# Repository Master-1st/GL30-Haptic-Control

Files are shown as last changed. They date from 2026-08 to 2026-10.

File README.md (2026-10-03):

# GL30 Haptic Control

**2026-10-03 update:** [Current offline delivery](docs/offline-delivery-20261003-cn.md), [Altium PCB guide](docs/pcb-drawing-guide-20261003-cn.md), and [A-board native schematic snapshot](hardware/pcb/stm32-foc-a-altium-r6/README_CN.md). Current ESP32/STM32 host suites have 8/15 cases respectively; frozen firmware builds passed. This candidate is unflashed and the custom PCB is not laid out or routed.

English · [简体中文](README_CN.md) · [Documentation](docs/README.md) · [Roadmap](ROADMAP.md) · [Contribute](CONTRIBUTING.md)





**Give rotary controls a programmable feel.**

GL30 Haptic Control is an open-source haptic knob project in development for desktop controls, creative tools, and everyday interactions. Built around a CubeMars GL30 brushless motor, an encoder and closed-loop control produce virtual detents, damping, spring return, and soft limits.

The aim is to let one knob change its feel with the application: distinct steps for volume, smooth movement through a timeline, or resistance at a parameter's boundary. A round display provides context, while physical feedback helps you feel the operation.

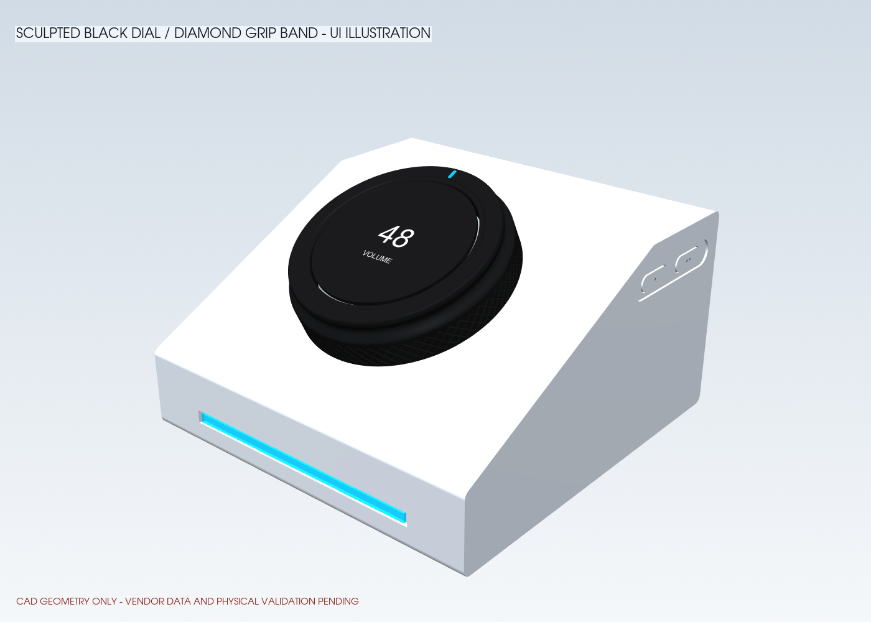
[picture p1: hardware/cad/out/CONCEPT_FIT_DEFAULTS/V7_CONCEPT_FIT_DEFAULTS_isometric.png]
GL30 Haptic Control concept


*Existing concept render, not a finished-device photo. It does not include the new press mechanism or bottom light ring.*

## Different actions, different feel

- **Detents:** configurable positions and strength for selection and stepped adjustments.
- **Damping:** resistance for continuous control, from careful adjustment to faster movement.
- **Spring return:** a centered interaction for exploring playback speed or directional input.
- **Soft limits:** resistance at parameter boundaries, making a range tangible.

These behaviors are organized around **Haptic Profiles**. The goal is to separate the feel an application requests from low-level motor control, so developers can adjust configurations and compose interactions.

## What could you use it for?

These are priority application directions; their software and whole-device integrations are still in development.

| Application | Intended interaction |
| --- | --- |
| **Volume and media** | Stepped volume, on-knob status, and press-to-control playback |
| **Focus timer** | One revolution sets one hour; orange progress rings represent additional turns, with press-to-start/pause |
| **Video and creative tools** | Timeline navigation, frame stepping, and parameter adjustment with task-specific feel |
| **Smart home** | Control lights, temperature, or scenes through platforms such as Home Assistant |

GL30 is the first reference device. The longer-term direction is to bring these haptic configurations and application interfaces to other physical controls. See the [feature research](docs/feature-research.md).

## Screen, light, and motion

The interaction direction combines a black rotary ring, a black screen surround, and RGB light emerging from the knob-to-base gap. At least 24 LEDs form a fixed ring: the illuminated position follows the measured knob angle instead of a painted marker. Pressing the ring provides confirmation and timer controls.

Expressive screen motion uses anticipation, elastic exaggeration, and rebound to respond to the user's actions. When off, the display should blend into the black surface.

The new press mechanism and light ring are not yet implemented in CAD or firmware. Board and assembly details belong in the separate [design plan](docs/knob-press-rgb-architecture-cn.md).

## A platform to build on

- **Separate control and UI roles:** STM32G474 handles the motor and haptics; ESP32-S3 handles the display, applications, and connectivity.
- **Inspectable configurations:** Profile formats, examples, and validation tools support experimentation with application-specific feel.
- **Start without hardware:** protocol checks, a device simulator, host tests, and a separately buildable UI model run on a computer.
- **Open project materials:** firmware, application-layer sources, protocol definitions, prototype CAD, and engineering notes have dedicated entry points.

## Current progress

The project is a **pre-alpha engineering prototype**.

- **Bench-tested:** bounded GL30/AS5048A closed-loop operation, basic haptic modes, and stop/communication-loss shutdown.
- **Available offline:** the current protocol, Profile validation, device simulator, same-source KK C UI, NVS preferences, control-owner handoff, and product-port protection regressions.
- **Engineering materials:** the seven-page A-board Altium schematic without test points, BOM and placement guide, plus R21 nominal mechanical models and the corrected assembly manual.
- **Next:** finish four A-board pad footprints and placement, complete B/C circuits, and validate the custom board, display, mechanism and assembled haptic feel on hardware.

This is not yet a ready-to-replicate kit. Bench results do not establish finished-device feel, thermal performance, battery life, or durability. See the [bench report](docs/bench-validation-20260908-haptic25-extended-cn.md) and [roadmap](ROADMAP.md).

## Start exploring

- [UI model and host preview](firmware-esp32/ui/README.md)
- [Haptic configuration compatibility](docs/profile-compatibility.md)
- [Prototype CAD and printing notes](hardware/cad/README_CN.md)

To run software checks from the repository root, use Node.js 24+ and pnpm 11.19+:

```bash
pnpm install --frozen-lockfile
pnpm verify
```

These commands check the protocol, Profiles, and simulator without hardware. They do not launch a GUI or drive a motor.

Go deeper: [STM32 motor core](firmware-stm32/README.md) · [PC Companion](pc-companion/README.md) · [Protocol](protocol/schema/protocol-v1.md) · [Documentation](docs/README.md).

## Help shape the feel

Contributions to haptics, application adapters, screen animation, mechanics, tests, and documentation are welcome. Use cases and reproduction reports are valuable too. Start a [Discussion](https://github.com/Master-1st/GL30-Haptic-Control/discussions) or read the [contributing guide](CONTRIBUTING.md).

[SmartKnob](https://github.com/scottbez1/smartknob) and [X-Knob](https://github.com/SmallPond/X-Knob) are important interaction references; sources are documented in the [feature research](docs/feature-research.md). GL30 hardware parameters and validation remain independent.

## License

Original material is licensed under [Apache-2.0](LICENSE). Third-party components retain their own licenses; see [THIRD_PARTY_NOTICES.md](THIRD_PARTY_NOTICES.md). Obtain vendor material from its [original sources](hardware/cad/vendor/SOURCE_MANIFEST.md).

This project is independent of the referenced vendors and projects and does not imply their endorsement.

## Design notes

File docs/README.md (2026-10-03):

# Engineering documentation

[当前离线交付](offline-delivery-20261003-cn.md) · [A 板怎么画](pcb-drawing-guide-20261003-cn.md) · [公开项目入口](../PROJECT_INDEX_CN.md)

当前进度先看 [2026-09-27 项目进度整理](project-progress-20260927-cn.md)；按模块查找见 [项目索引版](../PROJECT_INDEX_CN.md)。[项目全量单文件版](../PROJECT_ALL_IN_ONE_CN.md)含历史首批 BOM 和早期方案，不作为最新完成状态或整套采购指令。

原 `G:\Agent\workspace` 的 GL30 文件已归回项目，见 [统一入口与版本关系](../outputs/workspace-consolidated-20260927/README_CN.md)：包含 R12–R20、装配手册、正式板指南和独立发布准备工作区。9/27 已建立 [R21 合并机械候选](../outputs/r21-integrated-mechanical-20260927/README_R21_先看.md)，仍需实物验证。

A 板当前使用 [原生 AD 工程，无测试点](../hardware/pcb/stm32-foc-a-altium-r6/README_CN.md)、[AD ZIP 与验证](../outputs/a-schematic-altium-20260927/README_CN.md)：7 页、146 个位号，AD 实际连接比对通过；已关联用户库封装 142/146 个位号，仍有 4 个封装及 30 个驱动源警告，未完成投板审核。此前 [KiCad/PDF 版](../outputs/a-schematic-kicad-20260927/README_CN.md)是含测试点的历史源稿。PB9/PA12/PC13 与母线/NTC 已统一，固件验证见 [接口核对包](../outputs/product-interface-20260927/README_CN.md)。[OSHWHub 类似项目对照](../hardware/pcb/stm32-foc-a/开源项目对照.md)列出可参考部分及差异。

The detailed engineering notes are currently Chinese-first while the public repository overview and roadmap are bilingual. Contributions that add accurate English counterparts are welcome.

面向首次访问者的介绍见[中文首页](../README_CN.md) / [English overview](../README.md)。本次首页写法的[类似项目原文与改写对照](readme-reference-cn.md)单独保留，不与工程方案混排。

## Read in this order

最新屏幕状态及证据见 [9/27 汇总](project-progress-20260927-cn.md)：9/17 连续菜单记录 **59.980 FPS / 60 秒**，目标 60 Hz，显示错误、输入丢弃和电机发送均为 0；已加入彩色图标、中英切换及设置页。电机未参与此性能验收。[9/16 的 61.587 FPS 显示链审计](esp32-60fps-optimization-20260916-cn.md)和 [9/15 的 35.706 FPS 记录](esp32-dirty-audit-20260915-cn.md)保留为历史阶段证据，不能混合版本和测试条件。

早期产品交互方向见 [旋环按压、24 RGB 与板件装配方案](knob-press-rgb-architecture-cn.md)（2026-09-09）；后续机械实物反馈和正式板路线以 [当前汇总](project-progress-20260927-cn.md)为入口，均不自动继承台架验收。

最新离线实现见 [H26 行为层与 ESP 动画](haptic26-ui-offline-20260908-cn.md)：新源码未烧录，不继承 H25 的硬件验收。

当前实测先看 [2026-09-08 H25 扩展验收](bench-validation-20260908-haptic25-extended-cn.md)：37 组新增冻结采样、定时边界、ACTIVE STOP/失联关断、20 次重复运行和无出力通信/准备状态压力测试通过。此前 H25 电流阶梯见 [基线报告](bench-validation-20260907-haptic25-cn.md)，H8/H10 及中间失败保留为历史。

整体进度以 [9/27 汇总](project-progress-20260927-cn.md)为入口；[9/9 总进度](project-progress-review-20260908-cn.md)、[9/8 原始审查](project-progress-review-20260908-history-cn.md)与 [9/5 重评](project-reassessment-cn.md)保留为历史，不再作为当前源码或首测操作基线。

1. [`feature-research-cn.md`](feature-research-cn.md) / [`feature-research.md`](feature-research.md) — haptic-first product scope, public demand, integrations, and explicit non-capabilities.
2. [`current-architecture-cn.md`](current-architecture-cn.md) — active architecture and source-of-truth order.
3. [`evidence-boundary.md`](evidence-boundary.md) — what each evidence level does and does not prove.
4. [`hardware-gates.md`](hardware-gates.md) — staged release gates before energized testing.
5. [`cubemars-vendor-confirmation-cn.md`](cubemars-vendor-confirmation-cn.md) — unresolved motor/encoder questions.
6. [`stm32-pinout-and-schematic-cn.md`](stm32-pinout-and-schematic-cn.md) — current pin and schematic input table.
7. [`stm32-bringup-and-tuning-cn.md`](stm32-bringup-and-tuning-cn.md) — post-vendor bring-up and tuning order.
8. [`../hardware/motor-control/GL30_KV290_ARRIVAL_BASELINE_CN.md`](../hardware/motor-control/GL30_KV290_ARRIVAL_BASELINE_CN.md) — received motor parameters, consistency checks, safe defaults, and first-test gates.
9. [`waveshare-baseline.md`](waveshare-baseline.md) — application-module baseline.
10. [`NUCLEO + TI EVM FOC bring-up`](../firmware-stm32/bench/NUCLEO_G474RE_FOC/README_CN.md) — current HAPTIC25 NUCLEO-G474RE firmware, exact EVM/encoder pin map, restricted console and evidence boundary; ALIGN, short bidirectional IQ and eight-mode hardware smoke pass, not product/tactile acceptance.

Validation-board drawing and test instructions live under [`hardware/drv8316r_bench`](../hardware/drv8316r_bench/README_CN.md).

## Documentation rule

Plans, calculations, simulations, builds, CAD checks, bench measurements, and external reproductions must remain distinguishable. When a result changes, update the narrowest source document and link the raw evidence rather than copying the claim into several files.

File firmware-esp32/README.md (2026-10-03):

# GL30 ESP32-S3 屏幕固件

2026-10-03 公开上传入口：[当前源码与冻结离线交付](../docs/offline-delivery-20261003-cn.md)，[A 板画板指南](../docs/pcb-drawing-guide-20261003-cn.md)。本机 outputs 历史归档不全部随 Git 分发。

2026-10-02 冻结历史：[设置保存、STM32控制权交接与验证](../outputs/esp32-settings-storage-20261002/README_CN.md)。采用ESP-IDF NVS保存13项配置，启动恢复不恢复运行/授权状态；运行写入须有精确RELEASE回显和显示DMA独占。无对端不写Flash，握手完成作废旧ARM，恢复后须新人工请求。三配置各8/8、ESP-IDF构建通过，未烧录。线协议已统一72/44/24字节；千问第一轮架构意见与当前代码意见分别记录，最新实际评审范围见交付。本段评审仅描述该次冻结结果，不代表本次重新调用模型。

2026-10-02 零回显阶段历史：[只读确认、重复停止修订与验证](../outputs/esp32-zero-confirm-review-20261002/README_CN.md)。两路回显须在完整UART接受之后且年龄小于20ms；新STOP换nonce，旧回显不能恢复确认。该阶段三配置各6/6，未烧录；当时未接NVS，已由上方续进实现。软件回显仍不是实体关桥证据。

2026-10-02 输入链路阶段：[停止请求、64位ARM令牌与回归](../outputs/esp32-input-stop-review-20261002/README_CN.md)。`MOTOR OFF`在解析时先提交停止，输入队列满时也立即记录撤授权；停止前开始的半行或排队ARM会失效。溢出清理取消手势并清队列，须在清理后重新发ARM；普通OFF后新的人工ARM仍可被接受。三种主机配置各6/6、专项294项检查与ESP-IDF构建通过，未烧录；最后复核至UART提交间隙的在途帧不能召回，不声称物理停机延迟。该阶段Qwen按当时要求关闭，当前授权规则以上方新包为准。

2026-10-02 状态显示续进：[电机状态、灯效入口、同源画面与验证](../outputs/esp32-motor-feedback-20261002/README_CN.md)。底部显示 OFFLINE/CHECKING/ALIGN/READY/ACTIVE/FAULT/UNKNOWN 及中文提示；有效 FAST 接收年龄达到 20 ms 时投影为失联，读取快照再次检查。失联时的诊断零值表示没有当前证据，不能据此清故障或授权。状态只更新显示，不暂停计时、不取消手势。八项菜单的“设置 → 灯效”入口已按普通输入走通。主机检查和 ESP-IDF 构建通过，本版未烧录。

2026-10-02 电机链路续修：UI与 READY/ACTIVE FAST 健康时，未 armed 也发送固定 nonce 的零限值心跳；STM 同步将有效零限值定义为撤使能/关桥，正常空闲不会因停止发包而锁存通信故障。MOTOR OFF、反馈失配或健康失效后，通信恢复不能自动授权出力；正常页面切换保留已有人工授权。产品仍未对齐时不发送该心跳。见[源码、回归、构建与审查记录](../outputs/idle-fault-and-link-review-20261002/README_CN.md)。本轮未烧录，未测FPS或实体电机手感。

2026-09-27 界面修订：[代码审查、前后画面与验证](../outputs/esp32-ui-review-20260927/README_CN.md)。主目录已合入归并资料中的桌面/月历调整，并统一灰度字体、菜单图标和圆屏设置布局，修复多圈反转蓝灯位置与中文标题缺字。主机和浏览器检查、ESP-IDF 构建通过；本轮未烧录，旧版本 FPS 不代表这版性能。

[9/17 发布准备工作区](../outputs/workspace-consolidated-20260927/firmware/GL30-Haptic-Control-release-20260917/docs/firmware-status-20260917.md)保留独立 Git 关联和未提交内容；仅合入上述 UI 相关文件，没有用整个工作区覆盖当前主目录。版本关系见 [整理入口](../outputs/workspace-consolidated-20260927/README_CN.md)。

当前实际固件入口为根目录 ESP-IDF 工程：`main/app_main.c` → `components/gl30_ui` → `KK_UI` → RGB565 版 `KK_OLED` → CO5300/CST820 BSP。目标为 Waveshare ESP32-S3-Touch-AMOLED-1.32，466×466。

[当前进度与 9/17 最新验证记录](../docs/project-progress-20260927-cn.md) · [9/16 60 FPS 显示链优化与代码审计（历史阶段）](../docs/esp32-60fps-optimization-20260916-cn.md) · [9/15 按帧跳过比较与代码审计（历史基线）](../docs/esp32-dirty-audit-20260915-cn.md) · [9/15 菜单与性能优化（历史阶段）](../docs/esp32-menu-optimization-20260915-cn.md) · [9/15 自动校时](../docs/esp32-auto-clock-and-kk-animations-20260915-cn.md) · [9/15 USB 实机调试](../docs/esp32-usb-bringup-20260915-cn.md) · [9/14 接入、构建与边界](../docs/esp32-kk-integration-20260914-cn.md) · [固件同源预览说明](ui/kk-preview/README_CN.md)。预览显示同一份 C 代码的实际画布。此前 `ui/src` 的 LVGL 组件和 `ui/preview` 的 SVG 演示是历史设计参考，不在新固件构建链路内，也不是运行时备用实现。

2026-09-15 已连接 Type-C、备份原始 8 MB Flash，并通过 COM11 烧录与读取 USB 状态。CO5300、CST820 和 PSRAM 初始化已在实机日志中确认；实屏目视、色序、触摸方向和实际触摸手势仍待确认。闹钟、手感与天气联网保留待接入状态。当前已编译接入默认未使能的 STM32 菜单链路，20 项 USB 功能与连续菜单测试中 `motor_tx=0`；没有烧录 STM32 或驱动外部灯环。

9/15 已验证当前 Windows 用户的 Type-C 自动校时程序与复位恢复；Wi-Fi/SNTP 尚未接入。KK_UI 保持 Custom 页面与统一刷新调度，软件菜单复用 Q12 缓动，电机 q/f 反馈直接决定视觉相位。9/16 完成 wire-native RGB565、80 MHz QSPI、64 行传输、三帧缓存及后台清屏等优化，见 [该阶段审计](../docs/esp32-60fps-optimization-20260916-cn.md)。9/17 进一步加入彩色图标、双语和设置页，当前目标为 **60 Hz / 16,667 μs**；最新连续菜单测试 **59.980 FPS / 60 秒**，`frame_errors=0`、`input_drops=0`、`motor_tx=0`。这是屏幕链路记录，尚未完成人工视觉、实际手势、真实 STM32 满流量与电机手感验收；详见 [当前进度中的原始记录与边界](../docs/project-progress-20260927-cn.md)。

已冻结接口：

- USART 5 Mbaud、8N1、全双工 DMA；不实现旧草案的 6 Mbaud。
- Waveshare J1-11 `ESP TX -> STM PB11 RX`。
- Waveshare J1-12 `ESP RX <- STM PB10 TX`。
- GP1 接经开漏缓冲后的 `SYS_FAULT_N`；GP0 首版 DNP；GP2 禁止外部驱动。
- ESP UART0 启动日志必须关闭或移动，不能污染 V1 二进制链路。
- 3.3 V 电源不通过扩展口互相回灌，只共地和信号。

后续硬件闭环：验收实屏与触摸后，联调已有 UART0 接入及新增 HAPTIC_STATE 生效反馈。屏幕固件默认不授权出力；只有显式调试使能后才可能建立有力矩的菜单会话，健康 READY/ACTIVE 链路可先发送零限值心跳。编译和主机仿真不代表实体电机已验收。计时器回旋目标和零点止挡意图已经在界面模型中计算；电流环与触觉闭环仍由 STM32 承担，不能用触摸输入或电机端角度观察自动冒充手动施力。

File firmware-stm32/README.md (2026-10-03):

# GL30 STM32 固件：产品工程与 NUCLEO 联调工程

2026-10-02 当前离线续进：[控制权交接与完整验证](../outputs/esp32-settings-storage-20261002/README_CN.md)。普通命令匹配64位租约，ACQUIRE后先接受精确全零命令，RELEASE期间关闭输出并暂停周期遥测而保留保护/故障；第二临界区重新检查10ms命令年龄。三种主机配置各15/15，CET6产品和NUCLEO台架构建均0错误0警告。产品电角零位宏仍为0，本轮未烧录、不放行出力。

当前两个硬件目标均由 STM32CubeMX 生成，使用 Keil MDK-ARM 与 ARMCLANG 6.21；外设和高频路径采用 STM32 LL。它们是不同硬件端口，不是历史版本。旧 HAL/CMake ARM 工程不作为活动路径。

**手上是 NUCLEO-G474RE + TI DRV8316REVM 时，从 [FOC 联调工程](bench/NUCLEO_G474RE_FOC/README_CN.md) 开始。** 板上为 HAPTIC25：20 kHz 电流环、AS5048A SPI、受限 ALIGN/双向 IQ/八模式已通过实测。2026-09-08 追加定时边界、重复运行、运行中 STOP 和失联关断，详见 [扩展验收](../docs/bench-validation-20260908-haptic25-extended-cn.md)。不要把下面 CET6 产品板工程烧到 NUCLEO，也不要混用引脚表。

## CET6 产品板当前实现

- 160 MHz；TIM1 40 kHz 中心对齐互补 6-PWM，默认死区 500 ns。
- TIM1 CH4/TRGO2 同步 ADC1/2/3 注入采样；40 kHz FOC/SVPWM。
- TIM6 4 kHz 角度观测，TIM7 2 kHz 触觉与安全调度。
- DRV8316：SPI3 Mode 1、5 MHz；USART3：5 Mbaud DMA；I2C1：400 kHz。
- DRVOFF 上电关断、TIM1 MOE 默认关闭、PB12/TIM1_BKIN 低有效、故障锁存。
- 9/27 已购器件接口统一：PB9 为 MOTOR_PWR_EN，PA12 为 nSLEEP，默认均低；PC13 低速推挽驱动 U7，未就绪/故障为低。母线 ADC 倍率 11，10k/B3950 NTC 在 200 Hz 任务换算。
- 产品编码器实现为 `drivers/factory_encoder_as5048a.c`，复用共享 AS5048A 编解码：SPI1 Mode 1、16 位、2.5 MHz，TIM6 4 kHz 执行 ANGLE→DIAG→NOP。角度和诊断回复均检查奇偶校验与 EF；异常不刷新最后成功的时间戳。整轮 50 µs 为超时判据，实板时序尚未验收。只读接入不解除供电、驱动配置及电角零位门控。
- 10/02 驱动复查：SPI3 增加 FIFO 上限、共用超时和 CS 间隔；配置与 arm 可被故障取消。普通停转保留配置，实际休眠/断电前明确使其失效；arm 不再自动清障。致命异常入口增加紧急关断。见[本轮修订、三方审查与验证](../outputs/driver-startup-review-20261002/README_CN.md)。

## CET6 产品板 CubeMX/Keil 工程

10/02 电流采零续修：移除驱动休眠时的开机平均，改为配置/电源/休眠资格检查、10 ms 稳定等待、512 组三相样本与均值/波动验收；掉电或故障清除零偏，50 ms 期限也由前台检查。过压保护在采零之前执行，零偏的三通道快照在临界区内取得。见[采零阶段证据](../outputs/current-zero-review-20261002/README_CN.md)。

10/02 启动流程续修：逻辑、温度、编码器和新鲜 ADC 合格后，固件自动请求母线；母线连续稳定 10 ms 后唤醒驱动，等待 10 ms、配置读回、完成采零，再在 MOE=0/六路 PWM 输入低的条件下确认驱动状态。仅首次 NPOR 可受控确认一次，其他故障不自动清除；失败后关断且不重试。此准备过程不会开启 PWM，出力仍要求电角零位合格及 ESP 的显式启用。当前电角零位仍无效，未烧录、未验收实物时序。见[本轮实现及验证记录](../outputs/power-startup-review-20261002/README_CN.md)。

收到的命令记录本地接收时刻；排队达到 10 ms 的命令不刷新通信心跳，首次 READY 之前接收的命令不能触发 arm。开机 50 ms 仍无新鲜 ADC 会锁存故障；故障态只有在输出与电源请求均读回关断、2 kHz 安全调度仍有进度时才继续喂狗。IWDG/WWDG 复位会在下一次准备前锁存启动故障，避免自动重试供电。主循环或安全调度失去进度仍由看门狗复位。

10/02 空闲与停止续修：准备完成且 DRVOFF 实际为低时，2 kHz 监督和前台监测会锁存共享 PB12 低；verify 返回到 COMPLETE 发布前也复查。普通关桥的 DRVOFF 高不会被该检查误判；重新启用事务中，仅当实际 MOE 和驱动输出均关闭时暂由驱动最终读回把关，避免把正常释放稳定期误判。一旦任一输出指示开启即继续监视，事务返回后标记清除。TIM7 不新增 SPI/等待。有效零力矩上限命令刷新租约并立即撤 arm、清零 FOC、关桥，不能使能 PWM；正限值保留原门控。ESP 健康空闲时发送零心跳，失效后不自动恢复出力。见[本轮证据与审查](../outputs/idle-fault-and-link-review-20261002/README_CN.md)及[协议约定](../protocol/schema/protocol-v1.md)。未烧录，电角零位宏仍为0。

- 产品 IOC：`cubemx/GL30_AMOLED_V7/GL30_AMOLED_V7.ioc`
- 生成脚本：`cubemx/generate.ps1`
- Keil 工程：`cubemx/GL30_AMOLED_V7/MDK-ARM/GL30_AMOLED_V7.uvprojx`
- 应用入口：`app/gl30_app.c`
- 默认硬件参数与引脚：`config/board_config.h`

需要重新生成时，在仓库根目录运行：

```powershell
Set-Location firmware-stm32\cubemx
.\generate.ps1 -CubeMxPath 'C:\path\to\STM32CubeMX.exe' -FirmwarePackagePath 'C:\path\to\STM32Cube_FW_G4_V1.6.3'
```

也可以设置 `STM32CUBEMX_EXE` 和 `STM32CUBE_FW_G4` 环境变量后直接运行脚本。脚本内部使用 CubeMX `-q`，并在启动前后检查 CubeMX 进程，已有实例时立即失败；不要使用 `-h`，也不要手工并行启动多个 CubeMX。生成后脚本以文本方式幂等加入 ARMCLANG 6.21 和 `Application/GL30`，不会用 XML 重写器破坏 `.uvprojx`；本机固件包路径只在本次生成中使用，结束后恢复仓库中的 IOC。

Keil 中打开上述 `.uvprojx` 后执行 Rebuild；命令行验收示例：

```powershell
Set-Location firmware-stm32\cubemx\GL30_AMOLED_V7\MDK-ARM
$keil = (Get-Command UV4.exe -ErrorAction Stop).Source
$args = @('-r', '.\GL30_AMOLED_V7.uvprojx', '-t', 'GL30_AMOLED_V7', '-j0', '-o', '.\build-ac6.log')
Start-Process $keil -ArgumentList $args -WindowStyle Hidden -Wait
```

2026-09-27 本地产品工程 rebuild 结果：ARMCLANG 6.21，`0 Error(s), 0 Warning(s)`；程序占用 `Code=38952, RO=672, RW=16, ZI=61040`。日志、接口静态核对和测试见 [本轮验证包](../outputs/product-interface-20260927/README_CN.md)。这是构建证据，不是实物运行证据；本次修订没有发布到 GitHub。

9/27 已用 CubeMX 6.18.1 重新生成成功：修正 `ADC12CLockSelection/ADC345CLockSelection` 键名大小写，移除 ADC 空值及未启用的 RCC RNG/USB 派生字段。ADC 实际时钟保持 PLLP 40 MHz；任何新增生成错误仍需检查，不能把日志中的错误一概忽略。USART3 DMA 在运行时配置，所以两个 DMA 中断向量由 `app/gl30_app.c` 持有，避免 CubeMX 删除。

## 主机测试

2026-09-28 复查已修复产品 BKIN 两级极性、DRV8316 状态判定、TIM2 回绕竞态、UART DMA 接收边界和编码器非有限角度准入；[历史复查记录](../outputs/stm32-review-20260928/README_CN.md)。BKIN 源不反相（LL 源极性 HIGH/BKINP=0），最终刹车 LOW/BKP=0。当时三种主机配置各 10/10、静态检查 24/24。2026-10-02 增加真实产品 SPI1 端口及独立故障注入测试，见[本次接入与验证记录](../outputs/project-advance-20261002/README_CN.md)。

```powershell
cmake -S firmware-stm32/tests -B build/stm32-host -DCMAKE_BUILD_TYPE=Debug
cmake --build build/stm32-host --config Debug
ctest --test-dir build/stm32-host -C Debug --output-on-failure
```

当前注册 14 个测试程序：通用 host、FOC 数值安全、bench safety、硬件诊断、应用诊断、触觉行为、CORDIC，以及产品 TIM2、DRV8316、UART RX、AS5048A SPI1、采零状态机、实际 ADC 中断采零和供电准备路径。产品编码器测试编译真实驱动的 MCU 分支，仅替换 LL 外设和时钟；一般 `GL30_BUILD_ONLY` 构建仍保持 INITIALIZING/无效，不能伪造硬件就绪。主机测试不验证 MCU 中断时序或电气波形。

10/02 DRV8316 专项扩展至 111 项检查：旧源码先复现 FIFO、迟到读数和 DRVOFF 取消问题，修订后 Windows Debug、Linux ASan/UBSan、Release＋LTO 各 11/11；产品与 NUCLEO ARM 重建均 0 错误、0 警告。日志保存在上方驱动修订包。普通停转后的成功重新 arm、故障时拒绝 arm、原 PRIMASK 保持均有模拟验证；不把假外设时间当成 MCU 测量。

## 产品板实物验证前的硬边界

- PA4 是上电高电平 CS，PA5/PA6/PA7 为 AF5 SPI1；PC14/PC15 保留。MISO 串联 1 kΩ 按原理图选用 2.5 MHz；边沿与编码器小板本地去耦仍须实物核验。
- PB9/nSLEEP 只在复位及准备条件未满足时保持低；条件满足会自动准备母线和驱动，但不会开启 PWM。不要再按“全程不会拉高电源请求”的旧版本假设接板；当前没有烧录此版本，准备流程也需无电机限流验收。
- 不允许绕过 `control_ready()`、编码器有效门或安全监督器强行开 MOE。
- 可完成代码阅读、协议/状态机测试、公共原理图、保护链评审和 CAD 包络检查。
- 不能宣称已验证编码器协议、相序、电角零位、电流比例、闭环稳定性、温升、回灌或手感。

以上限制针对产品板硬件端口；不应误读为 AS5048A 型号/协议仍未知。现在可以用 NUCLEO + TI 评估板进入受限实物首测，但需要接板后的检查和独立验收。

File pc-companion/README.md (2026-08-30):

# PC Companion

当前已有协议/Core/Profile/设备模拟。后续先完成 5 Mbaud 原始录制与回放，再接 PresentMon、传感器、Trace Viewer 和更新器。

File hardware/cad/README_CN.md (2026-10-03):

# GL30 参数化 CAD

## 当前 R8 独立机械审查修改

2026-09-12：最新产品机构见 [R8 修改与验证入口](../../docs/full-assembly-r8-review-fixes-cn.md)。外形104×98，单MGN7、1:1短同步带、独立固定1.32英寸屏幕；补齐名义安装链，修正轴/三臂架、侧键、导轨、电机、止挡及线束。模型只供无电样件验证，不等于正式加工或带电放行。

## 历史 1.2 mm PCB 布局版本

2026-09-10 已完成 [三块 1.2 mm PCB 板框与装配设计](../../output/models/GL30_PCB_1P2/设计说明_CN.md)：A/B 为 98×34，C 为 Φ74/Φ56 带耳、最大 74×84；新壳 118×114，前高20、后平台58。采用 LPHD5919096 3S 电池尺寸基准，固定连续灯环取代实体蓝标和前灯条。

入口为 `pcb_packaging.py`，提供 STEP、DXF、分件和四页尺寸图。已做机械空间检查；没有完成 PCB 布线、按压传力/回弹、充放电、热或光学实测。详细边界见上述说明。

## 原 V7 96×96 模型归档

下文是原 `CONCEPT_FIT_DEFAULTS` 及其打印试样记录。当前产品板框与电池舱以 1.2 mm 布局版本为准，旧模型不随本次导出覆盖。

> 2026-09-09 的[旋环按压与底部 24 RGB 方案](../../docs/knob-press-rgb-architecture-cn.md)尚未写入本目录模型。下述输出仍包含旧实体角度标记/前灯条，不是新结构的打印或加工放行图。

当前发布标签：`CONCEPT_FIT_DEFAULTS`。模型用于数字装配阶段验证官方部件包络、无线电池/电子包络、结构层次和默认清距；已附带试制设计评审工图，但不是整机生产/加工放行文件，也不是载荷/寿命/热/电池安全验证。

## H2D / 灰色 PETG 先行验证

本轮优先给已经到货的电机使用[三件式实物夹具](../../output/models/GL30_MOTOR_FIXTURE/ASSEMBLY_CN.md)：底座、安装板、一体式传扭握环，各一件。STL/3MF/STEP 在同目录。它连接真实 GL30；仅供低电流短时联调，螺钉伸入量和实物安装必须检查，不含固定屏/电池，不是完整产品壳体。

已提供独立的[打印验证包说明](../../output/print/GL30_H2D_PETG_VALIDATION/START_HERE_CN.md)：五档键孔试片、键帽、加强版独立握持旋环、敞底1:1静态外形。每件都有 STL 和模型型 3MF，先打试片再打整机外形。

这是从当前 STEP 派生的非通电样件，不改变正式 CAD：独立旋环内径改为50、整机旋环和假屏固定、底部敞开取支撑。仅验证造型/握持/侧键位置和打印间隙，不能试轴承配合、旋转力反馈或真实按键回弹。生成脚本为 `make_petg_validation_kit.py`，独立回读检查为 `check_print_meshes.py` 和 `check_print_bambu_import.py`；不附带 G-code。

## 本轮产品结构修订

外观不推翻：黑色收腰旋环、蓝色短标、黑屏过渡肩、浅银底座、隐藏侧键与前灯条继续保留。壳体底面现为开口，增加独立底盖 `bottom_cover`（89.4×89.4×3，单边名义缝0.30）。四孔中心为 `(±40,-29)`、`(±40,14)`，Ø3.4通孔、底侧Ø6.7×1.65深90°沉头座；壳体有一体连接柱和对边5.8螺母槽。候选M3×10沉头螺钉+M3螺母，实物配合待验。

`torque_carrier` 与 `fixed_spider` 各已连接为单实体。实际产品电机/屏幕安装、环帽/袖套传扭连接、轴承配合和载荷仍未完成；几何连通不代表结构强度合格。项目推进顺序见[复盘与当前方案](../../docs/project-reassessment-cn.md)。

## 当前默认方案

- 壳体：`96 × 96 mm`，前缘 `20 mm`，后缘 `52 mm`；相对旧 `128 × 100 mm` 占地减少 `28%`。
- 有效操作面：`26°`，水平投影 `65.6097 mm`；后部平台 `30.3903 mm`。
- 旋环中心：距前缘水平 `39 mm`，中心高度 `39.0216 mm`。
- 旋环：外径 `54 mm`、内径 `40 mm`。
- 固定屏幕边框：外径 `39 mm`；与旋环名义径向运动间隙 `0.50 mm`。
- 独立支撑预留：NSK 6808 尺寸包络 `40 × 52 × 7 mm`。这只是为独立承载预留空间，未冻结品牌、密封形式、游隙、配合、预紧或 BOM。
- 普通按键：保留四键，左右各两键移至侧后方浅槽；改为同壳色的11×4胶囊键，键面内收0.30，使用低对比单点/双点标记；正面不放普通键。真实开关/行程/回弹待设计。
- 电源与服务：后侧独立凹入式电源/QON 键，键面低于后壳 `0.30 mm`；底部针孔仅用于 BOOT/RESET；后侧只保留一个充电兼 USB2 数据 Type-C，位于电池上方的电子板高度。
- 灯光：正面底部保留 `64 × 2.4 mm` 嵌入式状态/氛围灯扩散窗，表面内收 `0.10 mm`；后侧点状 LED 只作为充电/关机状态提示。
- 电池：后仓 `84 × 24 × 20 mm` 安全包络，来源是公开 `3S 800 mAh / 80 × 20 × 16 mm` 窄型电池尺寸再向每面增加清距。它不是冻结电池或 BMS。
- 配重方向：电池放在旋环/电机后方，可用于抵消前部组件的倾覆感；正式重心必须在电芯、BMS、PCB 和外壳材料选定后实测，当前几何不能证明已经平衡。
- 电子板：电池上方 `84 × 24 × 8 mm` 概念包络，与电池包络垂直间隔 `3 mm`。
- 电机和屏幕：直接导入供应商官方 STEP，不用圆柱占位冒充。

6808 尺寸依据：NSK 官方产品页 <https://www.nsk.com/engineering/6808-apn.html>。实际轴承选择仍受用户载荷、摩擦预算、配合和寿命计算约束。

电池包络参考：Grepow 公开的 3S 800 mAh 高倍率包尺寸为 `80 × 20 × 16 mm`：<https://www.grepow.com/rc-battery/classic-series-airsoft-battery-pack.html>。正式产品必须重新选定带独立保护/均衡/NTC 的电芯方案；公开 RC 包尺寸只用于当前 CAD 占位。

## 外观与配色要求

本轮按用户要求，把直筒矩形侧影改为收腰、微外翻上缘和圆顺肩面；下半圈保留宾利参考方向的浅菱纹，中央黑屏与一体黑色过渡环保持统一。参考图只决定外观，不引入汽车的尺寸、商标、实心结构或换挡机构。

### 用户硬约束

- 旋钮可见旋环与外部固定底座／底板必须明显异色，旋钮是视觉主体；这里的底板不是 PCB。
- 在屏幕关闭、灯条熄灭时仍应能一眼区分旋环与底座，不能仅靠灯光、窄装饰线或同色不同表面处理制造区别。
- 不采用全黑、全银等整机同色方案，也不以黑色配近黑深灰代替明确的双色对比。
- 旋钮整体黑色，蓝色只用于旋环位置短标记；中央屏幕关机时尽量融入黑色顶面，不保留显眼的银色屏幕边圈。

### 选定参考与取舍

参考：[宾利官方驾驶模式旋钮图片](https://www.bentleymotors.com/en/models/technology.html)，官方图注为 Continental GT Speed。本项目借鉴其菱形侧纹、窄边圈和分层轮廓，不照搬镀铬配色、车标或永久功能刻字。

- 侧壁：下半圈是平顶浅菱纹握持带，上半圈改为光滑收腰及圆顺上缘，避免从上到下同一直径、同一纹理。不是尖顶金字塔，也不是给薄壁轴承套强行压制深滚花的加工指令。
- 顶面：屏幕、旋环、过渡环均用同一黑色基调，依靠浅台阶与适度反光区分层次，不加银色屏幕框。
- 过渡环：直接做在旋环帽的内缘，随旋环转动，不新增松动的装饰零件。它从原 `Ø40 mm` 内孔边缘径向向外占用旋环本身的材料，不填塞 `0.50 mm` 运动缝，不盖住 `Ø39 mm` 中央固定盖板。
- 底座：保留明显异色的浅银／哑光固定外壳；内部电机、屏幕、轴承、电池基准及外壳包络不改。
- 标记：只保留一条蓝色短位置标记，随旋环转动，不等于编码器零点；不增加顶部灯环。
- 前底部灯条、四个侧键、后置电源键及后置单 USB-C 均保留。

### 当前配色（按用户指定）

黑色旋环与黑色中央固定面板，搭配浅银色喷砂／哑光底座。蓝色仅作为旋环顶面的短位置标记，不是把旋环整体做蓝，也不是新增顶部灯光。原有正面底部状态灯条仍保留；关机预览将灯条和后侧状态灯显示为熄灭状态。

继续保留正面底部灯条和后置电源键；普通四键的位置、键帽、浅槽与通孔已修订，内部电机/屏幕/轴承/电池基准不改。颜色、光泽、槽形和握持舒适度须经样件确认，下列数值是可修改的建模默认值，不是加工冻结。

### 隐藏按键和试制工图

新增[工图、公差和配合说明](ENGINEERING_DRAWING_NOTES_CN.md)，并提供[六页A3试制评审PDF](../../output/pdf/GL30_Current_Prototype_Drawings_CN.pdf)。这是带真实STEP投影、剖面和尺寸的设计评审图，不是整机加工放行文件；轴承配合、开关机构和未完成的结构连接均明确HOLD。

### 已建入几何的外观细节

- 两组 `±45°` 浅斜槽，每方向周向 `64` 道；周向节距约 `2.65 mm`，名义槽口宽 `0.55 mm`，交叉后总径向去除深度上限仍为 `0.20 mm`，不是两向深度相加。
- 纹理只保留在 `ring_sleeve` 的法向 `z=1.6…7.0 mm` 握持带，套的上下各留 `0.80 mm` 光面；名义谷底半径不小于 `26.80 mm`。最下外角增加 `0.20 mm` 小圆顺收边，半径同样不低于 `26.80 mm`。轴承孔、电机与屏幕基准不变。
- `ring_cap` 外壁用三段相切的三次 Bezier 母线回转成形：从轴承上方 `z=7.8 mm / R27 mm` 收到 `z=10.4 mm / R25 mm`，再微外翻到 `z=12.0 mm / R25.5 mm`，最后圆顺进入 `z=13.2 mm / R24.9 mm` 的较窄顶面。最大外径仍为 `54 mm`，法向总高仍为 `12.4 mm`。收腰全部位于轴承上方，不削薄轴承座。相切不等于已经完成表面曲率、美观或触感打样。
- 内缘保留 `1.20 mm` 径向宽的黑色过渡肩，台面下沉 `0.20 mm`，外侧用 `0.30 mm` 径向斜面衔接旋环顶面，内侧也有短倒角。过渡肩不是屏幕保护圈或承载件。
- 较窄顶面上的蓝色圆头短槽为 `2.8 × 1.0 mm`，深 `0.10 mm`，与顶面齐平；径向中心 `R23.2 mm`，端点半径为 `21.8 / 24.6 mm`。STEP 中的 `ring_index_mark` 是填漆体积的示意，不是新增机械镶件或 LED；默认位于模型 `+Y` 的 12 点钟方向，跟随旋环转动，不代表编码器零点或所有软件场景的绝对位置。
- 旋环主顶面与固定黑色盖板均保持法向 `13.2 mm`；过渡肩台面位于 `13.0 mm`，仅有浅凹层次，不抬高整机，也不抬升屏幕。
- 原轴承外套名义壁厚 `0.90 mm`，开浅槽后槽底名义余厚 `0.70 mm`。这是避免削穿当前几何的约束，不代表薄壁强度、阳极氧化后尺寸或可加工性已通过。
- STEP 保存黑色旋环、蓝色填漆标记、黑色固定盖板与银色底座；PNG 由同一 CAD 几何渲染。反光、阳极色与喷砂效果仅为预览，不等于真实材质样板。

### 关机隐藏屏幕的做法与边界

中央使用一整片 `Ø39 × 0.5 mm` 固定盖板，覆盖显示区及其周围黑边；盖板下面的固定环形支撑厚 `0.5 mm`、开口 `Ø33.8 mm`。支撑底部仍在法向 `12.2 mm`，盖板底部 `12.7 mm`，顶面 `13.2 mm`，与旋环顶面齐平。盖板不跨过旋转接口，固定盖板与旋环仍有名义 `0.50 mm` 径向运动缝，不能做成粘在一起的一整块面板。

光学方向是深色透光显示窗配合盖板下的黑色遮光边，让熄屏区与边框黑度、光泽接近；不能直接用不透光黑漆覆盖有效显示区。CAD 把整片盖板显示为黑色，是外观目标，不是透光率、屏幕亮度或反射率模拟，更不证明实物已经达到息屏一体黑。

工艺机制参考：[AMT 的 All-Black 覆层说明](https://www.amtouch.com.tw/en/product/all-black-coating.html)，其采用黑色边框与半透明黑色可视区，并建议光学贴合。该说明针对其 LCD／触控方案，不是本项目 AMOLED 的适配证明，也不代表当前 CAD 的空气清距可直接当成胶层厚度。

打样需确认：关机后正面／斜视／强环境光下能否看出显示边界；开机亮度、颜色、可视角及触摸灵敏度是否可接受；盖板材质、透光率、遮光油墨、表面处理、胶层和支撑强度。当前 `0.5 mm` 盖板与支撑只是几何默认值，尚未冻结材料及工艺。亮屏外观图使用白色 `VOLUME / 48` 示意，文字仅用于渲染，不进入 STEP，也不表示固件已实现该界面；关机专图不显示 UI，同时关闭状态灯，仅蓝色实体标记保持可见。

本轮覆盖当前模型输出，不增加版本或发布标签，也未推送 GitHub。`assembly.step` 是完整数字装配；`exterior.step` 是同一造型的轻量外观文件，不包含电机、显示板及内部概念包络，不能用于内部装配核对。

### STEP 导出完整性

原始 Waveshare STEP 的整体拓扑检查不通过，但其中的实体全部有效。显示板源文件除 `403` 个实体外，另含 `266` 个不属于实体的面。装配导出保留这 `403` 个实体及电机的全部 `7` 个实体，不导出供应商文件中的非实体面；不推断这些面的物理用途，也不改写或删除厂家原始 STEP。

所有安装包络／清距仍根据完整原始模型核算，另检查实体导出前后包围盒一致。详见几何报告 `vendor_step_exports`。这项处理用于实体交换格式的可靠性，不代表 SolidWorks 实机打开、零件配合或可制造性验证。

## 生成方法（Windows，隔离环境）

```powershell
py -3.12 -m venv .venv-cad
.\.venv-cad\Scripts\python.exe -m pip install -r hardware\cad\requirements.txt
.\.venv-cad\Scripts\python.exe hardware\cad\v7_product_model.py
```

本机已有可用的隔离 CAD 运行时，不需要重新安装软件。生成完成后，用独立的 STEP 回读检查验证实际文件，而不只相信生成过程：

```powershell
.\.venv-cad\Scripts\python.exe hardware\cad\check_step_exports.py
```

回读结果保存为当前目录的 `V7_CONCEPT_FIT_DEFAULTS_step_readback.json`。这不是 SolidWorks 桌面兼容性实测。

脚本会生成：

- `V7_CONCEPT_FIT_DEFAULTS_assembly.step`：包含官方 GL30 与 Waveshare STEP 的装配模型。
- `V7_CONCEPT_FIT_DEFAULTS_exterior.step`：轻量外观实体模型，优先用它快速查看配色和槽形；内部件不在此文件中。
- `parts/*.stl`：外壳、旋环壳、耦合盘、固定支撑等概念件。
- `V7_CONCEPT_FIT_DEFAULTS_geometry_report.json`：尺寸、来源、包络和断言结果。
- `V7_CONCEPT_FIT_DEFAULTS_isometric.png`：外观视图。
- `V7_CONCEPT_FIT_DEFAULTS_powered_off.png`：屏幕、前灯条和后侧状态灯熄灭的外观目标，非光学仿真。
- `V7_CONCEPT_FIT_DEFAULTS_exploded.png`：同轴堆叠/载荷路径视图。
- `V7_CONCEPT_FIT_DEFAULTS_side.png`：侧面包络视图。
- `V7_CONCEPT_FIT_DEFAULTS_rear.png`：后置电源键、单 Type-C、麦克风与状态灯视图。
- `V7_CONCEPT_FIT_DEFAULTS_ring_detail.png`：收腰圆肩、下部菱纹带、一体过渡肩、蓝色标记与固定盖板的局部视图。
- `V7_CONCEPT_FIT_DEFAULTS_ring_profile_side.png`：以旋钮自身轴线为基准的正交侧视图，直接检查收腰和上缘轮廓；不是整机斜面角度或制造剖视图。
- `V7_CONCEPT_FIT_DEFAULTS_button_detail.png`：同色浅凹侧后按键与灰色点标记；丝印仅用于渲染，不增加STEP机械实体。
- `drawing_geometry.json`：从实际STEP提取的工图几何、试制公差、HOLD项目及源文件哈希。

CadQuery/OCP 7.8.1 在 Windows CPython 3.12 处理大型 STEP compound 后，解释器析构阶段可能访问冲突。脚本在所有文件关闭并刷新后，仅在 Windows 用 `os._exit()` 跳过该已知析构阶段；构建失败仍会在生成完成前抛错并返回失败。

## 本次自动检查结果

- GL30 官方 STEP：轴向 `28.2000 mm`，最大半径 `17.2500 mm`。
- Waveshare 官方 STEP：厚度 `11.3000 mm`，包含连接器/突出特征的最大半径 `19.3125 mm`。
- 屏幕官方完整几何到旋环内径的最小径向余量：`0.6875 mm`。
- GL30 完整几何到 3 mm 内底面的轴向投影余量：`2.1644 mm`。
- 旋环到斜面/后平台折线的水平余量：`2.3423 mm`。
- 电池包络与官方 GL30：实体交集 `0 mm³`，Y 向包围盒间距 `1.7830 mm`。
- 电池包络与中心支撑：实体交集 `0 mm³`。
- 后置电源键面凹入 `0.3000 mm`；Type-C 外形到电池包络的垂直间距 `5.3000 mm`。
- 正面底部灯条存在且内收 `0.1000 mm`，与内底面和斜面均满足当前几何断言。
- 四个普通键均在左右侧面，另有一个后置电源键和一个后置 Type-C。
- 菱纹套的斜槽交汇处及相邻平顶执行多高度、全周实体内／外采样，另用贯穿整个套高度的受保护圆柱检查总槽深和下部圆顺边，不能只验一条槽。外壳、旋环套、旋环帽、蓝色标记、固定支撑边框及盖板均检查为单个有效实体。
- 旋环不侵入轴承包络，套与帽无体积重叠；新收腰、上缘、顶面半径各做 `16` 方位的实体内／外点检查，防止旧直筒仅凭相同最大外径就被误判为新版。检查内过渡肩的两侧斜面及整圈台面；过渡肩不侵入原 `Ø40 mm` 内孔，保持屏幕运动清距。
- 厂家部件全部有效实体保留，实体导出前后的包围盒一致；原始参考文件保留不动。
- 蓝色标记尺寸、齐平高度、与旋环接触且无体积重叠，以及黑色固定盖板的范围、齐平关系、旋转间隙和显示板清距纳入本轮检查；结果以当前几何报告及导出回读为准。
- 本轮生成 `56/56` 项通过；新增两支架连通、底盖实体和干涉检查，保留四键单实体、内收及静止/向内0.40空间检查（不是实际行程）。菱纹套内外采样 `256/256` 对通过，新收腰、上缘和顶面各 `16/16` 方位通过。盖板与旋环距离不小于 `0.5000 mm`；盖板底到官方显示模型最前表面的法向余量约 `0.4000 mm`；盖板与旋环主顶面名义高差 `0 mm`。套与帽的轴向范围通过实体剖切复核，不把曲面保守包围盒的外扩误判为材料重叠。
- 独立回读轻量外观 `22` 个组件／`22` 个实体、完整装配 `30` 个组件／`438` 个实体，两份文件各 `35/35` 项通过。新增底盖尺寸、向下拆卸空间、四孔及沉头座/螺母槽检查。保留真实浅槽/通孔、槽边侧壁和四键尺寸/位置/移动空间、拓扑、实体有效性、组件名称、颜色、真实菱纹、剖面、过渡肩及运动清距检查。回读盖板至内圆柱面距离 `0.5000 mm`。每个 STEP 的 SHA-256 与检查结果一起写入 `V7_CONCEPT_FIT_DEFAULTS_step_readback.json`，以该报告的 `all_checks_pass` 为准。
- 回读文件的整机包围盒为 `96.0 × 97.2 × 63.0304 mm`，包含脚垫等突出部分；侧键不再向外增加总宽，主壳体占地仍为 `96 × 96 mm`。厂家原始 STEP 的 SHA-256 未改变。未在 SolidWorks 桌面中实测打开。

这些数值只证明当前数字模型不违反已写入的包络断言。电池包络不是电池认证，电子包络不是完成 PCB；编码器出线扫掠、安装面方向、中心孔用途、轴承载荷、热路径、膨胀空间和实物公差仍未知。

两支架已修复多实体问题，但仍为产品概念支撑件，不能据完整 STEP 宣称载荷传递已验证。本轮未用未经核实的淘宝驱动板替换当前电子板包络。

## 厂家回复后优先修改

1. 确认 GL30 3-M3 / 4-M3 的定子、转子和出线侧，必要时翻转电机并重跑检查。
2. 加入真实编码器线束/连接器弯折包络。
3. 确认 `Ø6 mm` 通孔能否容纳固定支撑/线束。
4. 根据允许径向、轴向载荷和实际用户载荷，决定取消独立支撑，或正式选定轴承及配合。
5. 用选定的 3S 电池、BMS/保护板、功率板、逻辑板、扬声器、麦克风、单 USB-C 和紧固件真实 STEP 替换当前包络。
6. 用电池充满/欠压、边充边用、关机反拖与最大回灌实测结果决定是否扩大电池和外壳；不得先凭续航焦虑改成 30–40 Wh。

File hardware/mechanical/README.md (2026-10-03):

# Mechanical

> 2026-09-09 新方向为旋环按压、底部至少 24 RGB 与灯光角度标记，见[板件与装配方案](../../docs/knob-press-rgb-architecture-cn.md)。以下是改动前的 CAD 包络，不含浮动按压/底部光腔；不能据此认为新版已能打印装配。按压硬限位、独立载荷路径及遮光间隙须重新验证。

当前机械输出为 `cad/out/CONCEPT_FIT_DEFAULTS`：无线壳体 `96 × 96 × 20–52 mm`，四个普通键在左右侧面，正面底部保留 `64 × 2.4 mm` 内嵌灯条，后置凹入式电源键，单后置 Type-C，并包含 `84 × 24 × 20 mm` 3S 电池与 `84 × 24 × 8 mm` 电子板包络。相对旧 `128 × 100 mm` 占地减少 `28%`；当前数字模型中电池与官方 GL30/中心支撑交集均为 `0 mm³`。

电池位于旋环/电机后方，可作为后部配重方向使用；由于电芯、BMS、PCB、扬声器和外壳材料的真实质量尚未冻结，目前不宣称重心已经平衡。

正式机械图必须等待 CubeMars 确认定/转子安装面、编码器出线、Ø6 中孔限制和允许径向/轴向载荷，并完成用户按压力、侧向力、旋转扭矩和寿命目标。6808 只作为独立支撑尺寸包络预留，不是冻结 BOM；编码器不得承担结构载荷。电池包络同样不是电池/BMS/热/膨胀/跌落验证，正式电芯 STEP 到位后必须重新跑碰撞。

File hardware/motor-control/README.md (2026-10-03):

# Motor Control

电机实物已到货。厂家参数、曲线一致性、星形线—线到相值换算、当前固件限流和首测门槛统一记录在 [`GL30_KV290_ARRIVAL_BASELINE_CN.md`](GL30_KV290_ARRIVAL_BASELINE_CN.md)。官方 STEP 与本次用户上传文件哈希一致，不重复保留历史副本。

当前画图输入为 `../../docs/stm32-pinout-and-schematic-cn.md`。ECAD 源文件建立后只保留当前版，不导入历史修订目录。

DRV8316R 低成本验证子板按 `../drv8316r_bench/SCHEMATIC_PCB_DRAWING_GUIDE_CN.md` 逐页绘制，并按 `../drv8316r_bench/BUILD_AND_TEST_CN.md` 验证。验证子板不包含工厂编码器，也不包含正式无线产品的 3S/BQ25798/BQ77915、电机高侧隔离和再生制动闭环，不能替代最终主功率板证据。

正式产品唯一首板路径为 `BQ25798 SYS → 外部双向高侧隔离 → INA228 → MOTOR_BUS → DRV8316R → GL30`，并在 MOTOR_BUS 上布置不依赖主 MCU 的制动电阻/MOSFET和过压 BKIN。SYS 路径必须与独立电池轨做实物 A/B，最终只保留通过的一种。

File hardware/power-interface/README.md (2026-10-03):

# Wireless Power Interface

> 2026-09-09 新增[底部至少 24 RGB 与三板拆分计划](../../docs/knob-press-rgb-architecture-cn.md)：灯环由独立受控电源支路供电，不接 DRV8316 VBK/AVDD 或显示模组电池口。LED 料号、实际电流、稳压器和连接器尚未冻结；当前电源/热预算须纳入这项新增负载后重验。

当前产品默认改为 **3S 电池供电的完整无线力反馈**。以下参数是无实物阶段的首板默认，不是量产冻结或安全认证结论。

## 唯一默认架构

```text
单个后置 USB-C（PD + USB2）
  ├─ CC → HUSB238，请求 15 V
  ├─ D+/D- → ESP32-S3 USB
  └─ 15 V → 输入保护 → BQ25798 3S buck-boost charger
                         ├─ BAT ↔ 3S 电芯组 + BQ77915 保护/均衡 + NTC
                         └─ SYS → 逻辑 Buck/LDO → ESP32/AMOLED/STM32
                                └─ 外部双向高侧隔离开关
                                   → INA228 → MOTOR_BUS → DRV8316 → GL30

MOTOR_BUS → 独立硬件比较器 → 制动 MOSFET + 脉冲电阻
          → 独立过压关断 / TIM1 BKIN
          → TVS 仅吸收短尖峰
```

选择 `SYS` 作为首板系统负载节点，是因为它是 BQ25798 官方定义的系统输出，支持输入与电池补电，也避免把电机负载混入 BAT 端后破坏充电终止判断。它**不是已经证明能承受电机回灌**：电机前保留外部双向隔离开关，MOTOR_BUS 保留独立制动耗能，首板必须做 SYS/BAT A/B 脉冲与回灌测试；失败则改独立电池母线，不保留双实现。

官方依据：

- [BQ25798：1–4S、5 A、buck-boost、power path、QON/ship mode](https://www.ti.com/product/BQ25798)
- [BQ77915：3–5S、独立保护、温度保护与自主均衡](https://www.ti.com/product/BQ77915)
- [DRV8316：4.5–35 V 工作、8 A 峰值三相驱动](https://www.ti.com/product/DRV8316)

Waveshare 模块的 3.7 V 单节电池口不进入产品电机电源链，正式装机时由主板稳压供电，避免两套充电器和两块电池互相反灌。

正面底部灯条属于逻辑电源域，建议由可关断恒流/负载开关驱动；关机时默认熄灭，仅后侧充电指示允许由常开低功耗域控制。灯条亮度、电流和对续航的影响必须在整机功耗表中单独测量，当前不冻结 LED 型号或数量。

## 首板默认参数

| 项目 | 当前默认 | 证据边界 |
| --- | ---: | --- |
| 电池串数 | 3S | 架构冻结；2S 升压和 4S 降压不作为首板 |
| 标称/运行电压 | 11.1 V；约 9.0–12.6 V | 9 V 力矩与速度待实测 |
| CAD 电池参考 | 800 mAh，公开尺寸 80×20×16 mm | 仅机械参考；正式电芯/包未冻结 |
| CAD 安全包络 | 84×24×20 mm | 已做数字零干涉，不是膨胀/跌落/认证证据 |
| 最低放电能力 | 5 A 连续、15 A/200 ms 脉冲 | 依据额定母线功率的保守起点；最终看母线实测而不是相电流直接换算 |
| 原型充电 CV | 12.45 V（4.15 V/cell） | 为寿命和回灌留余量；12.60 V 需在回灌测试后决定 |
| 原型充电电流 | 0.4 A | 约 0.5C，优先降低小壳体充电温升 |
| 低压警告/停止目标 | 9.6 V / 9.0 V | 与选定 BMS、电芯压降联调 |
| 当前固件高母线 warning | 13.2 V，仅看电压 | 已构建，但还不是针对 3S 回灌完成的策略 |
| 3S 回灌预警目标 | 12.8 V 且母线电流为负 | 尚未进入固件；先用台架确定噪声、方向和迟滞，不能作为唯一保护 |
| 硬件制动/硬关断 | 当前仍为 14.4 V / 16.0 V 初值 | 必须按 BMS、BQ25798 反向行为和回灌能量重算电阻及比较器 |

800 mAh 只是为了优先满足缩小体积并建立统一 CAD 包络。没有平均功率和目标续航前，不冻结 30–40 Wh；如果实测峰值压降、温升或续航不足，再以 `能量 = 平均功率 × 目标时间 / 可用比例 / 效率` 计算容量，并重新做整机碰撞，不凭感觉放大电池。

## 回灌不可省略的边界

GL30 被手指反拖、快速反向或主动制动时会向 MOTOR_BUS 回送能量。任何一种情况都不能单独作为安全答案：

- 电池未满不等于永远能吸收回灌；
- BMS 可能在满电、低温或故障时断开；
- BQ25798 的 5 A 充电能力不等于 SYS 可以吸收电机反向能量；
- TVS 只能处理尖峰，不能承担连续制动；
- MCU 软件关断不能覆盖掉电和程序失控。

因此制动电阻、MOSFET、硬件比较器和过压关断位于 `MOTOR_BUS`，在电机高侧开关断开后仍应能处理关机反拖。比较器偏置和泄放路径必须由 MOTOR_BUS 或独立常开安全域供电，不能依赖已经关机的主 MCU。

INA228 继续放在 MOTOR_BUS 入口：5 mΩ 四端 Kelvin 分流器，记录双向电流、功率、能量和电荷；它不能代替 DRV8316、外部比较器、BMS 或 TIM1 BKIN。

## 电源键与关机

- 后侧单独设置凹入式 `PWR/QON` 键，正面没有电源键。
- 关机时短按只唤醒/显示状态，长按约 2 s 由固件先停转、确认 DRV 安全，再命令 BQ25798 进入 ship mode。
- 关机状态按住 QON 约 1 s 唤醒；插入 USB-C 也可退出 ship mode。
- 超长按使用 BQ25798 的系统电源复位能力，硬件安全链继续保持 DRV 关闭；具体按键时序必须在 EVM/首板验证。
- 外部 ship FET、BMS 和充电器属于常开低功耗域；目标关机静态电流小于 100 µA，但当前没有实测证据。

## 首板必须通过

1. 9.0/10.5/12.45 V 下的目标触觉、母线峰值、相电流和温升。
2. 电池满电/低电、USB 插入/拔出、无电池时的启动和安全禁止。
3. 电机接 SYS 与独立电池轨的脉冲负载、充电终止和回灌 A/B；只保留通过的一种。
4. 满电手动反拖、快速反向、主动制动和关机反拖的母线电压/负电流/能量。
5. BMS OV/UV/OCD/SCD、BQ25798 故障、隔离开关失效和制动电阻过温注入。
6. Wi-Fi/BLE、USB2、AMOLED 和 40 kHz FOC 同时工作时的 EMC/丢包/复位检查。

在以上证据完成前，本文件只能支持 `WIRELESS_POWER_DEFAULT + CAD_CHECKED + BUILD_ONLY`，不能写成续航、力矩、热、回灌或产品安全已经验证。

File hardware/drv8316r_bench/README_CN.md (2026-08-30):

# GL30 DRV8316R 验证子板

## 1. 这块板解决什么问题

`GL30_DRV8316R_BENCH_V1` 是 GL30 AMOLED V7 的低成本电机驱动验证板，用来在正式产品主板投板前闭合以下接口和风险：

- STM32G474 的 6-PWM、SPI3、三路同步电流采样与 `TIM1_BKIN`。
- DRV8316R 的上电、SPI 配置/回读、`DRVOFF`、`nFAULT`、三路 CSA 和三相功率输出。
- 不依赖 CPU 运算的三相 SOx 窗口比较器，经 TIM1 硬件 BKIN 异步关断 PWM。
- `16.0 V` 母线硬件故障比较器和低有效 `HARD_FAULT_N` 线与链。
- 焊接、去耦、热、接地、反接保护、测试点和故障注入方法。

这不是正式产品主板，也不是官方 DRV8316REVM 的仿冒复刻。它减少的是“接口和保护原理不确定性”，不能预先替代实物的温升、EMI、再生能量、编码器、电机闭环或认证测试。

## 2. 当前冻结

| 项目 | 当前值 |
| --- | --- |
| 驱动器 | `DRV8316RRGFR`，SPI 版本；不得替换成 `DRV8316T` |
| 母线范围 | 以下均指 D1 后的 `VM`：有功率运行 `6.0–15.5 V`，标称 `12 V`；`5 V` 只作静态验证，`16 V` 应触发硬故障，`18 V` 只作 Hi-Z 限流耐受/阈值扫描上限 |
| 项目电流 | 软件 `1.6 A`；外部窗口首板名义 `1.8 A`，实测后换阻值；DRV 内部 OCP 只作短路层 |
| PWM | 6-PWM，中心对齐 `40 kHz`，固件初始死区 `500 ns` |
| SPI | Mode 1，`5 MHz`，16 bit，偶校验 |
| CSA | VREF=`AVDD`，零点约 `AVDD/2`，增益 `0.6 V/A` |
| 过流阈值 | 首板 `V_LOW≈0.573 V`，`V_HIGH≈2.727 V`；名义约 `±1.80 A` |
| 母线故障 | `VBUS_SENSE=VM/6`，`VBUS_TRIP≈2.668 V`，约 `16.0 V` |
| 安全默认态 | `nSLEEP` 有下拉和延时；`DRVOFF` 外部上拉；PWM 下拉；BKIN 低有效 |
| PCB | 约 `70 mm × 55 mm`，4 层；L2 连续 GND，VM 只在功率区局部宽铜 |

所有电压、电流、RC、阈值和死区都是首板输入值，必须按 [制作与测试手册](BUILD_AND_TEST_CN.md) 实测后才能冻结到正式版。

### 当前首板阈值取舍

- 接受的硬修订：`DRVOFF` 外部上拉由原架构的 100 kΩ 改为 `10 kΩ`。TI 给出该输入内部约 70–130 kΩ 下拉，100 kΩ 外部上拉会形成不可靠分压。
- 接受的边界修订：过流首板仍取名义 `±1.8 A`，但把 AVDD、CSA 和比较器公差都计入后，只能标为粗略 `1.47–2.17 A`；必须先实测再升到软件 1.6 A 上限。
- 不采用名义 2.0 A 默认值：它可避免 1.6 A 附近的安全侧误锁，但最坏动作点可能接近 2.4 A，偏离本项目约 2 A 的硬件保护目标。验证板优先接受“可能早停、可换电阻”，不接受“可能过晚保护”。
- 不在首板加模拟滞回或 TIM1 BKIN 数字滤波：当前硬件第一次低电平即清 MOE，自动恢复关闭，故障状态由固件锁存；首板先测毛刺和误触发。滤波会同时推迟真实 nFAULT/过流脉冲，不能无波形依据加入。
- 保留 nSLEEP 的 `10 kΩ/100 kΩ/100 nF`：计入芯片内部下拉及 3V3_CTRL 最低 3.1 V 后，稳态仍约 2.66 V，高于官方保证的 1.6 V 高阈值；同时保留约 1 ms 的上电顺序裕量。

以上取舍以 TI 官方资料、阈值最坏情况计算和可测停止条件为依据。Buck、低压余量、浪涌、上电顺序和反灌问题均已落实到当前指南；与官方参数冲突的建议不作为设计输入。

## 3. 为什么不是直接买官方 EVM

官方 DRV8316REVM 最适合做“TI 原板行为对照”，但不是完成 GL30 的唯一途径。自制板保留官方数据手册要求的 DRV 外围，并增加 GL30 必需的外部电流窗口比较器、`HARD_FAULT_N` 和直接 STM32 接口，成本主要集中在 DRV 芯片、两片比较器和 SMT 贴装。SOx 来自集成低侧电流检测，其有效区间和建立时间仍受 DRV 工作状态约束，所以该比较器不能替代 DRV 内部短路 OCP，也不能被描述为完全独立于驱动器的电流传感器。

有条件时借用一块官方 EVM 做 A/B 对照仍然有价值，尤其是排查自制 PCB 焊接、热或布局问题；没有官方 EVM 不妨碍完成静态、SPI、ADC、比较器和低压假负载验证。

来源不明、不给原理图且无法确认是 `DRV8316R` 的低价模块不接受。它通常缺少三路 CSA、`DRVOFF`、完整 SPI、可核算的外部过流保护或可追溯布局，省下的费用会转化成不可定位风险。

## 4. 文件入口

- [原理图与 PCB 画法](SCHEMATIC_PCB_DRAWING_GUIDE_CN.md)：按页、按引脚、按网络照着画；本轮按用户要求不代画 EDA 文件。
- [制作与测试手册](BUILD_AND_TEST_CN.md)：下单、焊接、接线、上电、注入、假负载和实电机推进顺序。
- [控制接口表](CONTROL_HEADER_PINOUT.csv)：2×10 控制头与 STM32 引脚逐项映射。
- `reference/ti/`：本轮实际取得的 TI 数据手册和 EVM 用户手册。
- [官方参考清单](reference/ti/SOURCE_MANIFEST.md)：来源、SHA256 与证据边界。

## 5. 设计边界

已能在无实物阶段完成：电气冻结、阈值计算、网络映射、画图规则、接线和测试门。KiCad 源文件、制造文件、BOM 位号与 ERC/DRC 由用户按本指南画完后产生，再交给本任务复审。

必须等实物：QFN 焊接质量、静态电流、各电源轨、SPI 波形、CSA 零点/增益、比较器实际阈值、BKIN 延迟、相节点过冲、二极管和芯片温升、低感假负载、工厂编码器接口、电角零位、真实电机和再生制动。

当前产品固件仍保持工厂编码器 `PENDING_VENDOR` 与 `GL30_ELECTRICAL_ZERO_VALID=0`，因此会持续禁止 arm、保持 `TIM1 MOE` 关闭和 DRV safe-off。这是正确的安全行为，不为验证板偷偷增加绕过。

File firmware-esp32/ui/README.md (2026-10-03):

# ESP32 界面与历史参考

当前运行和预览使用 `components/gl30_ui` 与 [kk-preview](kk-preview/README_CN.md) 的同源 C 画布；构建入口是 `ui/kk-preview/CMakeLists.txt`。下方 LVGL 模型和 SVG 目录是历史设计参考，不是当前固件或运行时备用路径。最新离线结果见[公开交付说明](../../docs/offline-delivery-20261003-cn.md)。

# UI (ESP32-LVGL)

该目录仅负责 **UI 表现层（模型 + 视图）**，不包含 UART、Motorcontrol、GPIO 或 OTA/Flash 路径。

硬件锚定：`Waveshare ESP32-S3-Touch-AMOLED-1.32`，显示分辨率 `466x466`。
官方基线显示链路记录见 `../../docs/waveshare-baseline.md`（LVGL v9，30 行双缓冲提示）。

## 1) Native C model API（无 LVGL 依赖）

- Header: `include/gl30_ui_anim_model.h`
- 输入类型：`gl30_ui_anim_input_t`
  - `volume`（0~100，默认 `42`）
  - `timer_minutes`（0~120，默认 `15`）
  - `timer_running`, `mode`, `wake_signal`, `off`, `connected`, `fault`
- 输出类型：`gl30_ui_anim_output_t`
  - 平滑后的 `value_ratio`、`dial_angle_deg`
  - `wake_level`
  - 文本：`value_text`, `mode_text`, `status_text`, `accessibility_text`
- API:
  - `gl30_ui_anim_model_init(gl30_ui_anim_model_t*)`
  - `gl30_ui_anim_model_tick(model, input, elapsed_ms, output)`
- 行为约束：
  - `NaN`/`inf` 输入被夹紧并降级到默认值
  - `off`：直接清空动态显示并强制 `wake_level=0`
  - `lost/fault` 只通过 `output->lost_connection` / `output->fault` 反映给视图
  - `gl30_ui_anim_model_tick` 可接受 `input == NULL`，此时视图进入断连显示（`connected=false`）

## 2) LVGL 视图（C）

- Header: `include/gl30_ui_anim_view.h`
- 生命周期：
  - `gl30_ui_view_create(parent, 466)`：创建 466x466 屏幕组件；`parent == NULL` 时挂到 active screen
  - `gl30_ui_view_render(view, output)`：按模型输出更新数值、角度、颜色、亮度
  - `gl30_ui_view_destroy(view)`
- 显示特性：
  - 黑底+蓝色弧线（`2D9DFF`），故障/断联会改变提示色
  - `off` 时变为黑屏
  - 本模块没有每帧显式堆分配，标签使用静态字符缓冲；不保证 LVGL 内部绘制过程零分配

## 3) 独立编译（离线/主机层）

```bash
cmake -S firmware-esp32/ui -B firmware-esp32/ui/build
cmake --build firmware-esp32/ui/build --config Debug
ctest --test-dir firmware-esp32/ui/build -C Debug --output-on-failure
.\firmware-esp32\ui\build\Debug\gl30_ui_host_model_demo.exe
```

不需要 ESP、LVGL 或串口，用于验证纯 C 动画模型；非 MSVC 平台链接数学库。

## 4) 启用 LVGL host preview

如果工程有可用 LVGL 源码：
```bash
cmake -S firmware-esp32/ui -B firmware-esp32/ui/build-host -DGL30_UI_BUILD_HOST_PREVIEW=ON -DGL30_UI_LVGL_SOURCE_DIR=<LVGL_SOURCE_DIR>
cmake --build firmware-esp32/ui/build-host --config Debug --target gl30_ui_host_demo
.\firmware-esp32\ui\build-host\Debug\gl30_ui_host_demo.exe
```

如无本地源码，也可用：
```bash
cmake -S firmware-esp32/ui -B firmware-esp32/ui/build-host -DGL30_UI_BUILD_HOST_PREVIEW=ON -DGL30_UI_FETCH_LVGL=ON
```

生成的 `gl30_ui_host_demo` 依赖 `gl30_ui_anim_view` 与同层模型层（仍为纯宿主 C 目标）。
拉取时固定到 LVGL commit `aa7446344c6ec7631112ef031983ef24077e24d5`（9.2.0），本轮实际主机构建使用同一提交。本地源码覆盖选项由调用者负责版本一致性。

程序在当前目录生成 `gl30_ui_host_awake.ppm` 和 `gl30_ui_host_off.ppm`，并验证刷新确实发生、亮屏含蓝色像素、熄屏全部像素为黑；失败退出非零。它是无窗口的真实 LVGL 渲染检查，不是 ESP 固件。主机 RGB888 全帧缓冲仅用于截图，不作为 ESP 内存/像素格式配置。MSVC 静态链接时移除上游 CMake 错加的 DLL 数据属性。

## 当前屏幕实现（2026-09-14）

新固件使用 [KK_OLED + KK_UI 的 C 同源预览](kk-preview/README_CN.md)，实际业务代码在 `../components/gl30_ui`。九项圆环菜单、表盘、彩色圈、可回调计时器、秒表与灯效已进入这条 C 实现。下方 SVG 和上方 LVGL 章节记录各自历史实现，不代表新固件状态。验证层级见 [本次接入报告](../../docs/esp32-kk-integration-20260914-cn.md)。

## 5) 浏览器 SVG 交互演示（2026-09-10，历史设计参考）

- 入口：`preview/index.html`，双击即可打开；操作与复现说明见 `preview/README_CN.md`。
- 原生 JavaScript 状态模型与 SVG 视图：黑色旋钮、固定圆屏、外环旋转/释放按压、四侧键、后键；图标/结构为 SVG，新增项目内置的 1254×1254 日照金山生成背景，运行无需远端依赖。
- 计时从零设定，一圈 60 分钟，演示上限 360 分钟，显示 HH:MM:SS。按最新用户反馈采用烤箱式自动回转，运行/暂停中可手动调时；连续灯带以蓝色标示前端，多圈分别着色；零点有模拟止挡。保留熄屏继续、首次按压仅唤醒与标注 450× 的 12 秒演示。
- 保留模拟音量/静音，加入失联/故障检查、键盘和减少动态效果支持。
- 照片式手表桌面（日照金山背景、本地时间/日期、示例天气）→黑底九项循环圆环菜单。前方图标放大、后方缩小，菜单灯光只有一个蓝色指针。计时器/音量保留；新增独立秒表、本地日历和天气示例，闹钟/手感/设置为占位页。单击确认、双击返回、长按未设置；后台倒计时和秒表继续，到时切回计时完成画面。
- `node --test firmware-esp32/ui/preview/model.test.cjs firmware-esp32/ui/preview/gesture.test.cjs` 运行纯模型与手势验收；浏览器导航、应用回归、触摸入口分别为 `verify-navigation.js`、`verify-interaction.js` 和 `verify-touch.cjs`。
- **2026-09-10 的历史边界**：当时没有把新 SVG 产品交互移植进 C，也没有生成或烧录 ESP-IDF 固件。上面的 C API、0–120 分钟和蓝色 LVGL 视图说明只适用于既有 LVGL 组件；当前 KK 固件见本文开头。
- 新增可操作灯效调整：四种效果、六种颜色、0–100% 亮度，旋转选项目/调值、单击进入/确认、双击逐级返回。设置即时生效；菜单保留单蓝指针，计时/音量保留数值光带，亮度统一生效。本次页面会话内保留，刷新恢复默认。验收见 `../../docs/lighting-mode-demo-20260910-cn.md`，脚本为 `preview/verify-lighting.js`。自动回转与止挡仍为网页模拟。

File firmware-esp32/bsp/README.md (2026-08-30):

# BSP

Waveshare ESP32-S3-Touch-AMOLED-1.32 的板级显示、触控、扩展口和电源初始化；不得在此层解析业务协议。

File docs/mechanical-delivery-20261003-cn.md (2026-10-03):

# GL30 机械模型与装配手册公开交付

本次上传沿用已有 R21 名义模型和 2026-09-29 修正版装配手册，没有再调整你已经多次打印的外壳、金属加工件或装配设计。

[下载入口](https://github.com/Master-1st/GL30-Haptic-Control/releases/tag/offline-code-20261003)

| 附件 | 内容 | 边界 |
| --- | --- | --- |
| `GL30_R21_models_20261003.zip` | 全机/纯机械装配 STEP、四种打印改件、J20 原 STEP/DXF、名义核验、原 README 与来源脚本 | STEP/STL/DXF 可单独打开；来源脚本仍依赖原工程 R17/R20。不是新的加工订单，也不是实物装配通过 |
| `GL30_R21_assembly_manual_20260929.pdf` | 已交付的 40 页、21 步装配图解，含修正后的装轴顺序和螺钉头型 | 按版本点数、实测配合和手转/按压试装；不包括 FOC 通电验收 |

公开下载采用英文文件名；内容与本机 `GL30_实物装配图解手册_R21_20260929修正版.pdf` 逐字节一致，没有重新生成或改页。

9/27 原 README 的到货状态保留为当时历史；后续用户已告知加工件到货，按修正版手册核对当前实物。M07 实厚、轴承配合、张紧、导轨平行和按压稳定性仍需实测。新增 PCB 板框没有随 R21 冻结。

公开 ZIP 是原文件的逐字节集合，附逐文件 SHA-256；同名 STEP/STL 表示同一件，不能按两个零件重复打印。当前板件绘制见[A 板指南](pcb-drawing-guide-20261003-cn.md)。

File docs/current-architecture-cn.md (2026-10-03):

# GL30 AMOLED V7 当前架构

2026-10-02 当前代码与交付见[离线入口](../outputs/project-goal-closeout-20261002/README_CN.md)：产品AS5048A端口、驱动/供电/采零保护链已实现离线候选；ESP32为KK_OLED/KK_UI同源界面，新增NVS设置保存及STM32/显示独占维护。三配置ESP32各8/8、STM32各15/15，固件构建通过；未烧录，CET6实体资格和整机手感仍未验收。下方按日期保留设计与台架历史，不能覆盖当前工程的实板边界。

> **2026-09-09 产品设计增量：**新增旋环按压、底部至少 24 颗 RGB、灯光跟随实测角度并替代实体标记。按 3 块自制 PCB 加显示/原厂编码器/电池保护组件规划，详见[板件与装配方案](knob-press-rgb-architecture-cn.md)。这次只更新方案与文档；下述既有 CAD、固件和台架验收不自动覆盖新增功能。

> **当前状态（2026-09-08 UTC）：`BOUNDED_BENCH_ACCEPTANCE_PASS`，产品仍为 pre-alpha。**
> NUCLEO-G474RE + TI DRV8316REVM + GL30/AS5048A 的 H25 已通过受限 ALIGN、双向 IQ、八模式 smoke 和新增状态机/通信压力回归，见 [扩展验收](bench-validation-20260908-haptic25-extended-cn.md)。

9 月 6 日静态 Buck 状态和 H8/H10 中间失败属于历史，不再作为“当前禁止所有台架输出”的状态；历史证据没有改写。台架通过不放行 CET6 端口、无线功率路径、AMOLED 整机、手感计量、热或回灌，也不替代外部 nFAULT→BKIN 整链实测。供电设定和 H25 保护阈值未更改；最终硬件关断证据见报告。

## 1. 活动目录

```text
GL30-Haptic-Control/
├─ firmware-stm32/          # STM32G474 电机、安全、保护、厂家编码器待确认边界
├─ firmware-esp32/          # Waveshare 显示/UI/音频/通信框架
├─ pc-companion/            # PC 协议、Profile、设备模拟、Trace/更新框架
├─ protocol/                # 当前线协议、跨语言金样和参考实现
├─ hardware/
│  ├─ cad/                  # 官方部件、参数化模型和 CONCEPT_FIT_DEFAULTS 输出
│  ├─ motor-control/
│  ├─ power-interface/
│  └─ mechanical/
├─ design/reference/current # 当前 V7 手册；不保存 V6 文件树
├─ docs/                    # 当前执行手册、闸门、厂家清单和时间表
└─ artifacts/               # 仅放当前验证产物
```

## 2. 产品机械链

以下为**既有 CAD**的机械链。新增按压方案改用独立承载的轴向浮动组件，灯环固定于底座；按压力不得默认经过 GL30 轴承、编码器或屏幕玻璃。原实体标记/前灯条由新方案取代，尚未改模；载荷、行程、遮光和装配空间须按专项方案重新核对。

```text
固定链：机壳/后支架 → GL30 定子（具体安装面待厂家确认）
        机壳/中心支撑 → 固定轴承内侧/固定边框 → Waveshare 屏幕

旋转链：手指 → 金属旋环 → 独立支撑包络 → 机壳
        GL30 转子 → 柔顺扭矩耦合 → 旋环
```

当前无线模型外廓为 `96 × 96 mm`、前缘 `20 mm`、后缘 `52 mm`，相对旧 `128 × 100 mm` 占地减少 `28%`。四个普通键移到左右侧壁（每侧两个），正面底部保留 `64 × 2.4 mm` 嵌入式状态/氛围灯条；后侧保留独立凹入式 `PWR/QON` 键，底部只留 BOOT/RESET 服务针孔，后侧只有一个 PD 充电兼 USB2 数据 Type-C。

当前模型预留 6808 尺寸包络，使用户载荷不默认经过 GL30/编码器；后仓同时预留 `84 × 24 × 20 mm` 的 3S 电池安全包络和 `84 × 24 × 8 mm` 电子板包络。电池包络与官方 GL30、中心支撑的数字实体交集均为 `0 mm³`。实际电池、轴承、配合、预紧、热路径和寿命没有冻结；如果厂家证明 GL30 轴承可带规定用户载荷，可删除独立支撑。

## 3. 无线电源链

```text
单个 USB-C：HUSB238 请求 15 V，同时保留 USB2 数据
  -> BQ25798 3S buck-boost charger / power path
     -> BAT：3S 电芯组 + BQ77915 保护/均衡 + NTC
     -> SYS：逻辑电源 + 外部双向高侧隔离
             -> INA228 -> MOTOR_BUS -> DRV8316 -> GL30

MOTOR_BUS -> 独立比较器 -> 制动 MOSFET/电阻
          -> 过压关断 -> TIM1 BKIN
```

`SYS` 是首板默认电机输入路径，不同时保留两套生产实现；它仍是 `HARDWARE_REQUIRED`，必须与独立电池母线做一次脉冲负载、充电终止和回灌 A/B。制动耗能位于隔离后的 `MOTOR_BUS`，在主 MCU 关机或电机高侧开关断开后仍要能处理反拖。Waveshare 模块的 1S 电池口不接产品电池。

当前机械参考为窄型 3S 800 mAh 包，不承诺续航。初始充电目标为 12.45 V/0.4 A，最低运行目标为 9.0 V；BMS、电芯、充电阈值、回灌阈值和正式容量均是 `PCB_HOLD + HARDWARE_REQUIRED`。

## 4. STM32 当前安全链

以下门禁属于尚未完成实板端口的 **产品 CET6 工程**；不是说 AS5048A 型号未知，也不表示 NUCLEO 联调驱动尚未实现：

```text
factory_encoder_pending
  -> status = PENDING_VENDOR
  -> valid = false
  -> encoder gate = false
  -> persistent warning + arm denied
  -> TIM1 MOE off + DRV8316 safe off

ACTIVE 后编码器 invalid/stale
  -> 4 kHz 监控锁存 GL30_FAULT_ENCODER
  -> TIM1 MOE off + DRV8316 safe off
```

产品硬件端口完成后仅接入已确定的 AS5048A SPI 驱动，不同时维护 ABI/PWM 多后端，不恢复 MT6835 路径。台架按 NUCLEO 工程既有联调流程推进，不等待所有未来产品载荷资料齐备。

其余可复用控制链：

```text
三相电流 ADC 同步采样
  -> 20 kHz FOC 首测基线（NUCLEO+TI EVM）
  -> TIM1 互补 6-PWM
  -> DRV8316

HARD_FAULT_N -> TIM1 BKIN -> 异步关断
ESP32 <-> USART3 DMA <-> 当前二进制协议
```

产品 CET6 工程与 NUCLEO RET6 联调工程使用同一控制内核、不同硬件端口，均由 STM32CubeMX 6.18.1 生成 MDK-ARM，外设和中断使用 LL。Keil ARMCLANG 6.21 已有两者的 0 错误/0 警告构建记录。NUCLEO H25 已完成真实电机受限 ALIGN、双向小电流和八模式定时 smoke；不再停留在 TI 静态配置阶段。产品 CET6 仍未完成实板端口验证。最新实测边界见 [H25 扩展验收](bench-validation-20260908-haptic25-extended-cn.md)；旧故障按历史记录保留。产品 40 kHz、EVM 20 kHz，不能互相代替参数或验收。

## 5. 当前冻结与 HOLD

| 项目 | 当前结论 |
| --- | --- |
| 产品电机方向 | GL30 工厂编码器版实物已到；7 极对和 `Kt=0.038 N·m/A` 作初值；官方网页与到货空载点对应 `255 rpm/V`，`KV290` 视为型号标签，不强制要求先测 Ke 作为首测前置条件 |
| 自制 MT6835 磁环 | 已从活动产品树删除 |
| 编码器固件接口 | `AS5048A + SPI`；NUCLEO 联调已有真实驱动；产品后端 `PENDING_VENDOR` 保留至产品硬件端口完成验证 |
| 编码器电气/连接器/供电 | NUCLEO H25 台架已有 AS5048A SPI/角度诊断和有限 ALIGN 实测；不等于完整角度精度、产品电气端口或连接器料号已确认 |
| 外壳/旋环默认几何 | `CONCEPT_FIT_DEFAULTS` |
| 无线电源拓扑 | `3S + BQ25798 SYS + 外部隔离 + 独立 MOTOR_BUS 制动`，候选工程基线；台架先用外部电源 |
| 电池容量、BMS、电芯与充电参数 | `PCB_HOLD + HARDWARE_REQUIRED` |
| SYS 电机路径的脉冲/回灌能力 | `HARDWARE_REQUIRED`；与独立 BAT 轨 A/B 后只保留通过者 |
| 四个普通键/灯光/电源键/Type-C | 保留左右各两键、后置 PWR/QON 与单 Type-C；新方向为旋环按压及底部至少 24 RGB，替代原前灯条与实体标记，尚未改 CAD |
| 自制 PCB 数量 | 规划控制板、功率板、RGB/按压板共 3 块；显示、原厂编码器及 BMS 另计，排布/层数/连接器尚未冻结 |
| 电机安装面、出线、中心孔、轴承 | `MECHANICAL_HOLD` |
| 实物 FOC/热/手感 | H25 受限校准、电流与模式 smoke 已通过；完整手感、速度跟踪性能、热、回灌及整机仍为 `HARDWARE_REQUIRED` |

## 6. 事实源优先级

**电路专项约束（用户要求，2026-09-05）：电路结论只能依据对应器件与评估板的官方手册、官方原理图。** 记录型号、文档编号/版本、章节或表格、适用条件；资料不足时标记待厂家确认，不以其他型号、第三方教程、商家介绍或 AI 回答替代。千问、DeepSeek 等仅协助核查，不作为改线、选电平、解释故障或解除保护的依据。手册规定、实测记录、待验证假设必须分开；软件通过不代表实板通过。

该约束已同步写入[主设计 MD](G:/Agent/GL30_AMOLED_V7_Product_Edition/design/reference/current/GL30_AMOLED_V7_Product_Edition_Design_Manual.md)开头，不提升版本。当前台架按 TI DRV8316 Rev B、DRV8316REVM SLVUBZ9B、ams AS5048 DS000298 v1-11、ST UM2505/MB1367 对应资料核对；实际波形和读数另见[联调验收记录](../firmware-stm32/bench/NUCLEO_G474RE_FOC/TEST_RESULT_CN.md)。

1. CubeMars/Waveshare/ST/TI/ams OSRAM 的对应官方手册、官方原理图；厂家书面回复作为待核验补充，不替代器件电气限制。
2. 对应硬件端口的当前代码/配置；EVM 操作参照 `firmware-stm32/bench/NUCLEO_G474RE_FOC/README_CN.md`，产品板参照 `firmware-stm32/config/board_config.h`。
3. `hardware/cad/v7_params.py` 与几何报告。
4. `protocol/schema/protocol-v1.md` 与金样。
5. 当前 V7 手册；若与官方资料冲突，以核对后的官方事实和当前工程为准。

最新进展和开源借鉴决策见 [2026-09-08 项目审查](project-progress-review-20260908-cn.md)。模型用途及早期取舍保留在 [2026-09-05 历史复盘](project-reassessment-cn.md)，其中旧首测条件不作为当前操作指令。

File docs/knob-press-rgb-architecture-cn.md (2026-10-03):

# 旋钮按压、24 RGB 缝隙灯环与板级装配计划

日期：2026-09-10。状态：**WEB_INTERACTION_IMPLEMENTED / PCB_MECHANICAL_LAYOUT / NOT_PCB_RELEASED**。

新增 [1.2 mm 板框与装配设计](../output/models/GL30_PCB_1P2/设计说明_CN.md)：A/B 98×34，C Φ74/Φ56 带侧耳；新壳118×114，采用101×20×18的3S电池尺寸基准。固定连续灯环已建模，仍未完成按压传力机构、PCB 布线和实物验证。

本文原三板方案由 DeepSeek V4 Pro 参与架构初审。9/10 用户反馈更新为手表式桌面、九项循环圆环菜单、单击确认/双击返回、烤箱式回转和连续灯带，已实现于浏览器，详见 [新版验收](orbit-menu-demo-20260910-cn.md)。菜单仅显示蓝色指针，计时/音量保留连续色带。原电路/CAD 事实和实机边界保留；没有操作电源、电机、接线或刷写固件。模型意见不是电路事实或实测证据。

## 1. 产品要求与边界

- 全黑旋钮、黑色屏与过渡环；无实体蓝色角度标签。底座形成连续扩散光带，**最前端始终为蓝色**，经过部分使用对应圈色，不应明显辨认出离散灯珠。
- 底座全周至少 24 颗独立寻址 RGB LED。首版按 **24 颗**布置，不把原直线灯条当成环形灯。
- 旋钮外环机械按压：桌面单击进入菜单，旋转在九项入口中循环选择，再单击确认；双击返回上一级，长按暂未设置。计时器和秒表内单击启停；中央玻璃不作为按压承力面。原四侧键或后电源键继续保留。
- 定时器一圈 60 分钟，时间显示 `HH:MM:SS`；第一圈橙色，后续圈使用不同颜色，外灯当前段与屏内当前圈同色。音量一圈 100%，屏内进度、蓝色前端与旋钮位置对齐。
- 定时器采用烤箱式交互：倒计时自动往回旋转，运行/暂停中均允许手动调整剩余时间；逆转减少、顺转增加。到零完成，不允许继续减小；向零点外施力时提供受限止挡反馈。网页仅实现模拟目标与受阻回弹，真实电机力矩、跟随和接管尚未实现/验收。
- 熄屏同时关闭氛围/指位灯为默认体验；故障提示由电源和安全策略另外定义，不承诺断电仍有光学指针。关机隐屏需要实际光学样片。
- 本计划取代旧“实体蓝标 + 前 64 × 2.4 mm 灯条”方向。Web 已实现本次交互；现有 CAD、图纸和 C/LVGL 不因网页更新自动变化。

## 2. 首版做几块 PCB

**决定：3 块自研 PCB。** 先把位置敏感的灯环和热/功率部分分开，便于局部改版。暂不额外增加灯控 MCU，不再自研磁编码器板。

| 编号 | 数量/来源 | 功能与位置 | 层数候选 |
| --- | --- | --- | --- |
| A 电机主控板 | 1，自研 | STM32G474、DRV8316R、CSA/ADC、编码器接口、安全链；固定底座，靠近电机走线入口 | 4 层 |
| B 电源接口板 | 1，自研 | USB-C PD/USB2 接口、3S 充电/电源路径、逻辑/LED 降压、电机隔离与回灌；靠后接口/散热区 | 4 层 |
| C 灯环/按压板 | 1，自研 | 24 RGB、局部去耦、检测开关；固定底座光腔，按压开关可布在环板伸出的小耳上 | 2 层 |
| D 显示应用模组 | 1，现成 | **Waveshare ESP32-S3-Touch-AMOLED-1.32**；固定在不跟转的浮动支架上，随按压微移 | 厂商设计 |
| E 原厂编码器板组件 | 1，随 GL30 | 保留 AS5048A；相对电机/磁体安装关系不变 | 厂商设计 |
| F 电池保护板 | 1，按带独立保护板的 3S 电池包规划 | 保护/均衡/NTC 方案待核；即使封在电池包内也计入装配 | 厂商设计 |

A–E 按 **5 个功能板组件**，连电池保护板按 **6 个板级组件**规划。现成模组内部确切 PCB 数需最终 BOM/实物核实；采购口径是“3 块定制板 + 1 显示模组 + 1 带编码器电机 + 1 合格带保护电池包”。NUCLEO/TI EVM 不计入产品板数。保护板不能省略，也不是由本轮凭空新增第四块自研板。

层数是工程建议，不是制造放行。原 CAD 的 84 × 24 × 8 mm 电子包络已由新三板布局替代；当前 A/B 上下排布、C 固定在旋钮周围，板厚均1.2。详细孔位和装配高度见新增尺寸图，仍需电气布局、热设计及实物插拔验证，不能直接发板。

## 3. 供电、信号与实时控制

| 链路 | 计划 | 尚待冻结 |
| --- | --- | --- |
| B → A | 受保护电机母线、逻辑电源、回流及故障/使能 | 压降、脉冲电流、连接器、回灌位置/线缆寄生 |
| B → C | 独立受控 `5V_LED` 与功率回流 | 降压/限流开关料号、软启动、故障限流、热预算 |
| A → C | RGB 数据及必要参考地；由低优先任务组帧、定时器/DMA 输出 | MCU 引脚、定时器/DMA 资源、所选 LED 波形 |
| C → A | 单个常开轻触开关输入；低能量检测回路 | 上拉、RC/ESD、连接器和去抖 |
| A ↔ D | 沿用既有 5 Mbaud UART 规划；按压与场景走应用事件 | 原协议新增载荷/频率需另行实现，不声称现有兼容 |
| E → A | 原厂 AS5048A SPI/角度有效性 | 产品线束、电平、端口验收，不更改原厂传感器几何 |

PB10 TX / PB11 RX 是 **STM32 侧** UART 名称；Waveshare 已有 GP1 故障、GP0 DNP、GP2 禁止外驱的接口约束。不得把本计划当成新增引脚表。灯位计算暂定 60–100 Hz 的低优先更新目标；LED 线码速率依所选器件，不能靠随意降速替代协议要求。禁止关中断逐位发送，DMA 竞争和最坏控制时序要再核查。

### 灯光电源预算

- 尚未冻结 LED。优先筛选可寻址小封装，并逐一核对电压、电平、全白电流、线码、复位时间、散热与供货；“WS2812 兼容”不足以冻结设计。
- **保守工程包络**：假设每颗 RGB 每色 20 mA，24 × 3 × 20 mA = **1.44 A**，5 V 时 **7.2 W**。这不是已选 LED 的指标，也不是持续运行目标。
- B 板先按 **5 V / 2 A 灯轨能力候选**评估，另计逻辑/显示负载及变换损耗；原 **不高于 1 W**日常平均目标须按连续铺色重新核算，不能复用仅亮 1–3 个灯位的旧负载假设。都需选料和样机测量确认。
- 亮度软件限幅不能代替电源硬件限流。C 板近端去耦/储能、连接器额定电流、上电浪涌与回路压降按器件手册和计算确定。
- 灯环**不取电于 DRV8316 的 VBK/AVDD 或显示模组的小电源口**；TI DRV8316 Rev B §8.3.4 / 表8-5的 Buck 推荐负载与限流阈值不可混为“可持续供灯电流”。该禁用是本产品隔离噪声/负载的设计规则。[官方手册](https://www.ti.com/lit/ds/symlink/drv8316.pdf)
- 3.3→5 V 数据缓冲候选 SN74AHCT1G125：官方 Rev P §5.3 为 4.5–5.5 V 供电、VIH 最低 2 V；这支持该电平转换方向，但**未据此证明输出掉电隔离**。需核对 OE 默认禁用、LED 电源与缓冲供电顺序、无电回灌和绝对最大额定值，未核完不放行。[官方手册](https://www.ti.com/lit/ds/symlink/sn74ahct1g125.pdf)

各板优先保持连续参考地，按回流分区布局，不任意割地。LED 大电流直接回 B 板电源回路，不经过 CSA/编码器的细地线；信号参考地随信号走。A/B 的回流连接、USB 屏蔽与机壳连接按实际原理图/布局核查，不能用一句“所有地单点接”代替设计。

原 3S/BQ25798 SYS/隔离/独立 MOTOR_BUS 制动候选不因加灯自动通过。制动回路需靠近受保护电机母线、校核跨板走线寄生；电池、灯轨、显示均不得吸收未经设计的电机回灌。

## 4. 灯光如何表示角度

24 灯中心间隔为 **360° / 24 = 15°**。这是物理光点间距，不是 AS5048A 的测量精度。以外壳固定方向定义零位，装配时标记 PCB 的 LED0（内部丝印即可）：

```text
theta = wrap360(direction × (encoder_deg - encoder_zero) + led_zero)
u = theta / 15
i0 = floor(u) mod 24
w = u - floor(u)
i1 = (i0 + 1) mod 24
I[i0] = B × (1 - w)
I[i1] = B × w
```

上式仅说明蓝色前端的邻灯插值，已转过区域另按圈色铺光。`direction` 为装配后校准的正负方向；`wrap360` 落在 [0,360)。蓝色前端应能从连续底色中辨认；两灯插值、颜色叠加、亮度/gamma 与扩散效果均须实测，视觉光心不保证严格线性。

硬件中的蓝色前端仍须来自**有效、未过期的实测角度**；电机目标与实测位置不一致时应明确跟随误差，不能把目标冒充实测。浏览器使用理想跟随的模拟角度，不能证明真实电机已跟随。输入失效/断链时隐藏位置光。

模拟定时坐标为 `剩余分钟 × 6°`，音量坐标为 `百分比 × 3.6°`。倒计时减小目标位置；明确的手动事件直接增减剩余时间，保留 running/paused 状态，到零转完成。反馈角度是只读观测，不得把自动回转再次累计成手动减时。真实系统如何区分主动回转和手动接管，需独立实现并验证，不能仅靠单圈编码器角度变化假定。

当前外灯规则：最新一圈的已走部分使用当前圈色，未被覆盖部分保留前一完整圈的颜色，蓝色始终标示前端；恰好整圈时显示该圈完整颜色而不是空的新圈。Web 允许六圈作为演示上限，不据此冻结产品上限。

单圈编码器无法重建断电期间的多圈运动。本版上电默认 idle，累计设置量从零开始，等用户设时；验证单圈角度后可显示当前位置，**不要求电机自行旋转找零**。保存计时值/断电恢复是独立后续功能，不由编码器单圈读数推断。屏内橙色多圈与下方 24 灯分工不同。

## 5. 按压机构与输入模式

### 承载方式

旋环使用独立承载轴承；轴承支撑、电机定子固定座、原厂编码器安装关系和中央屏支架，位于**同一不跟转、可轴向微动的承载架**。旋环相对该架旋转；整个架按下时平移，磁体与编码器的相对位置保持不变。灯环、底座、电源板不随按压移动。

手指 → 旋环 → 独立承载件 → 浮动架/弹性支撑 → 底座；过压由硬止挡承受。不能把手压传给 GL30 原轴承、编码器、屏玻璃、开关焊点或电池。现有“固定链”要重新建模；不能只在旧底面补一个按钮。

采用三点弹性支撑/防倾导向，避免三个刚性导柱因公差形成过约束。单轻触开关仅提供检测/触感的一部分，由不旋转压杆驱动。屏幕随架微移但不旋转，玻璃不承受手压；线束留轴向弯折余量，严禁缠绕、擦转子或牵拉 FPC。

**初样工程目标**：旋环触发力 2–4 N、外部总行程 0.3–0.5 mm。不是开关自身工作行程或加工公差；必须根据开关手册、弹簧、传动比、运动件质量、线缆刚度和止挡选型。按压方向沿旋钮轴线（现模型倾斜面法线），不是默认沿桌面竖直方向。

### 最小交互

| 场景 | 单击确认事件 | 旋转 |
| --- | --- | --- |
| 桌面 | 进入菜单；本地时钟/日期，天气为明确标注的示例 | 不修改后台应用 |
| 菜单 | 打开选中的九项应用之一；首次默认计时器 | 每项40°，连续正反循环，前方放大、后方缩小；灯只亮蓝色指针 |
| 秒表 | 开始/暂停/继续；清零有独立按钮 | 不改后台计时或音量 |
| 灯效调整 | 进入/确认效果、颜色或亮度调整；双击先退编辑再回菜单 | 选择字段或调值；四效果、六颜色、亮度每格5%，仅网页预览 |
| 天气/日历/占位页 | 信息展示，不触发后台应用 | 不改后台应用；天气示例、日历本地日期，闹钟/手感/设置未接入 |
| 设定 | 开始计时 | 一圈增加/减少 60 分钟 |
| 运行 | 暂停 | 自动回转；手动逆转减时、顺转加时，不重启计时 |
| 暂停 | 继续 | 停止自动回转，手动可调整剩余时间 |
| 完成 | 清零重设 | 零点不再减小；顺转进入设定，不自动开始 |
| 熄屏 | 仅唤醒，不顺带启动电机 | 等唤醒后按应用解释 |

9/10 最新用户要求取代旧“仅短按”规则：双击应用→菜单、菜单→桌面，桌面双击原地保持；返回不暂停或清零后台计时。浏览器按下/释放分别去抖 20 ms，短按释放后等待 300 ms 排除双击；第二次按下落在窗口内则等待它分类，不先执行单击再撤销。持续按住 650 ms 归为长按但不执行任何应用动作，释放也不补发单击；第二次长按会消耗前一次待定单击。长按暂不承担熄屏、返回或恢复功能，后电源键继续独立工作。

熄屏状态的首次单击或双击仅唤醒；故障时仍可进入菜单或返回，但不能开始/恢复/调值。故障暂停倒计时及秒表，解除后均需手动恢复；导航及熄屏本身不暂停二者。到时优先切入计时完成画面并取消旧手势，保持原熄屏标志。转动、导航、断连/故障状态变化、失焦等取消待确认的旧单击；故障或熄屏状态稳定后新输入仍按上述规则分类。上述门限与导航已实现于 [浏览器演示](orbit-menu-demo-20260910-cn.md)，真实开关、电机与固件仍待独立实现/验收。

单常开开关**不能区分断线与未按**，也不能可靠检测所有机械卡滞和过行程。本方案不虚构这些故障诊断。按压是应用输入，不是安全急停或解除保护的凭据。

## 6. 出光与漏光控制

1. **LED 藏在固定底座，不塞原旋环侧壁。** 现参数外径54 mm、6808占位外径52 mm，名义径向材料仅 (54-52)/2 = 1 mm，尚未扣间隙/纹理；新灯板外径、内孔、固定耳都要重排。
2. 采用“固定 LED → 光腔 → 连续扩散窗 → 环形窄缝”进行试样。外观要消除分段和热点，同时保留蓝色前端及圈色边界；隔光筋与扩散强度不能照搬旧单灯光点方案。连续 SVG 效果不是实际光学证明。
3. 发光窗口固定在底座，活动旋环有重叠遮光裙边/迷宫唇。内侧黑色挡光墙隔绝屏边、中心孔；USB、侧键、壳缝分别遮光。黑阻焊本身不是可靠遮光壳。
4. 出光口与机械运动间隙分开设计。最小间隙预算要扣除**最大行程、轴向跳动、倾斜和装配公差**，同时检查全周转动、偏心按压与止挡到底时仍不碰擦、不遮掉光点、不暴露 LED 裸光。
5. 漫射/遮光件定位固定，不靠胶挤进轴承或旋转缝；为拆装保留定位柱和锁紧路径。贴黑胶带可做试样，不能替代量产防脱/耐温方案。
6. 灰色 PETG/H2D 先验证体积和机械配合。最终黑色件/遮光材料与真实扩散窗另测；灰料不能直接证明漏光合格，PETG 弹性件也不能直接证明长期回弹寿命。

## 7. 装配顺序与最少验证

**装配顺序：** 先电机/原厂编码器与独立支撑组成浮动组件 → 无电检查旋转和按压 → 固定 C 板/隔光筋/扩散窗 → 固定 A/B 与电池隔仓 → 接有锁止、防呆的线束 → 固定显示支架及黑盖板 → 校准灯位零点/方向。螺钉长度、扭矩、轴承预紧必须依最终图纸/器件说明，不能由此计划给定。

首轮只做以下区分性检查；这不免除以后产品热、安全、回灌和寿命验收：

| 检查 | 最小做法 | 通过口径 |
| --- | --- | --- |
| 无电机构 | 全周旋转；旋环四象限偏心按压各10次；用实际候选开关和测力计/砝码记录力—位移及触发/释放点（工程筛查） | 无刮擦/卡滞；可回弹；止挡先于器件损伤行程；触发力包含浮动质量和线束影响；不把玻璃当按键 |
| 光带试样 | 单灯、邻灯、连续铺色及蓝色头，固定曝光，松开/按下两状态 | 无明显分段/热点；蓝色头可辨；屏边/USB/侧键无可见串光 |
| 灯位映射 | 手动转一圈及跨0°，检查方向、24灯顺序和插值 | 跟实际角度而非目标动画；停转稳定；24灯不是更高精度计量 |
| 供电/干扰 | 依所选器件上限逐级增加亮度，记录灯轨电流/压降/热和编码器状态 | 不超器件/连接器/热预算，不导致逻辑掉电或编码器异常；不能向未定料板强灌1.44A |
| 按压事件 | 慢按、快按、偏压、按住和上电已按下；同时读编码器 | 单次释放只触发一次，无连发；轴向动作不造成异常角跳/SPI错误 |
| 主动回转/接管/止挡 | 后续受保护台架分阶段验证，记录目标/实测角度、受限力矩与手动接管 | 不把回转反馈重复计时；到零不继续减小；无隐藏越界积累；不得用本次网页代替实机验收 |
| 掉电/断链语义 | 累计多圈后重启；输入断链 | 不伪造断电圈数；不以自动电机运动归零；灯位无效有明确显示 |

最省成本的下一件实物是**全尺寸浮动按压环 + 1/4 圈可替换光腔试样**，先用少量同料 LED 比较隔光筋/扩散窗，再确定24灯完整C板。正式C板仍不少于24灯；试样不是缩减产品规格。

## 8. 依据、未闭合项与协作记录

- 几何事实：[v7_params.py](../hardware/cad/v7_params.py)及[CAD说明](../hardware/cad/README_CN.md)。1 mm 是名义几何计算，不是可用灯具腔宽。
- 显示型号/接口：[官方1.32原理图](https://files.waveshare.com/wiki/ESP32-S3-Touch-AMOLED-1.32/ESP32-S3-Touch-AMOLED-1.32-Schematic.pdf)、[本地官方来源清单](../hardware/cad/vendor/SOURCE_MANIFEST.md)、[现有引脚说明](stm32-pinout-and-schematic-cn.md)。不能拿1.75型号代替。
- 电路事实只依据匹配版本的官方器件手册/原理图；新增电平/电源选择仍需核实。此前台架阈值和电路保护不变。
- 仍未闭合：24灯/开关完整料号、板形/层叠/接口、GPIO/DMA、机械载荷和公差、固定中心管许可、光学材料、功耗/热、BMS与回灌。
- DeepSeek 首轮任务：`20260909084403-dcaa60d2c97a`，Pro/high，完成中文初稿与三板方案审查；主线程纠正型号、引脚归属、板数口径、接地、开关诊断及功率测试措辞。
- 二轮任务：`20260909084835-d75ba8cd1bb1`，Pro/high，已完整完成交叉核查。采纳板件拆分、浮动按压、分区遮光和最少验证建议；主线程纠正并经二轮复核的内容包括屏幕型号、引脚归属、BMS 计数、接地回流、单开关诊断能力、LED 功耗估算、多圈计时语义和台架/产品证据边界。AI 审阅不是器件手册或实物验收。
- 原始模型回答属于审阅材料，不是实测报告。**本轮未重新构建/烧录/运行电机，未制造PCB，未提交或推送GitHub。**

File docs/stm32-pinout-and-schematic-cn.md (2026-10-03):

# STM32G474CET6 当前引脚与原理图输入

更新：2026-10-02。硬件依据为 **A-SCH-INPUT-20260914 已购器件版**；本文件覆盖早期“编码器未确认”表及 9/18 指南中冲突的 PB9 建议。目标始终是 STM32G474CET6 / LQFP48，不套用 NUCLEO 引脚。

当前使用 Altium Designer 的 [R6 无测试点原理图](../hardware/pcb/stm32-foc-a-altium-r6/README_CN.md)，继续引用本机用户库。旧 KiCad 源稿仅为历史输入与审查来源。审核后只布局、不布线；操作见[最新画板指南](pcb-drawing-guide-20261003-cn.md)，没有 PCB DRC 或实板通过的结论。

## 1. 现在按什么画

| 项目 | 统一后的用途 | 本轮代码状态 |
| --- | --- | --- |
| PB9 / 46 脚 | MOTOR_PWR_EN，请求上游电机母线 | 已取消 ADC 中断调试脉冲；推挽低电平启动，故障撤销请求 |
| PA12 / 34 脚 | DRV nSLEEP | 已设置推挽低电平启动；不是 USB 预留 |
| PC13 / 2 脚 | 向 U7 输入就绪/故障状态 | 慢速推挽，低表示未就绪；开漏在 U7 输出端，不在 MCU 输入驱动端 |
| PB1 / 17 脚 | 母线 ADC | 软件倍率 **11**；硬件比较器的独立分压仍为 6 |
| PB2 / 18 脚 | 10k/B3950 NTC | 已换成 NTC 方程；开短路及超合理范围锁温度故障，不使用 TMP36 公式 |
| PA4/5/6/7 | 已确认 AS5048A 的 CS/SCK/MISO/MOSI | 产品只读 SPI1 已实现；CS 默认高，SPI Mode 1、16 位、2.5 MHz；待实板波形/时序验收，仍拒绝出力 |
| PC14/PC15/PA11 | R6 明确 NC，无测试点 | ADC 触发使用内部 TIM1 TRGO2/OC4；不按旧预留说明恢复外部焊盘 |
| PB8 | BOOT0 | 本轮仍保留救援用途，未改作 LED 数据 |

**当前固件上电先保持关断，逻辑、温度、编码器和新鲜 ADC 合格后，会自动准备母线和唤醒驱动；准备不使能 PWM。** 母线稳定等待、配置读回、采零及驱动状态确认全部合格后，还需要有效电角零位及新显式命令才能出力。故障先关 PWM/DRVOFF，再撤销 nSLEEP 和母线请求，准备失败不自动重试；正常零扭矩不通过反复切电实现。当前电角零位仍无效，且未烧录这次修订，详情见[启动流程验证记录](../outputs/power-startup-review-20261002/README_CN.md)。

MOTOR_BUS 上的独立再生制动必须位于上游隔离开关的下游，并在逻辑掉电后仍能工作。这是电路要求，尚无本轮硬件验证；仅关母线不能证明反拖安全。

## 2. 完整 48 脚硬件表

下表来自已购器件版结构化输入。它描述接线用途；“编码器用途确定”和“产品固件端口已实现”是两件事。

| 封装脚 | MCU 脚 | 原理图模式 | 网络 | 连接说明 |
| ---: | --- | --- | --- | --- |
| 1 | VBAT | 电源 | VBAT_3V3 | R1接3V3；C1去耦 |
| 2 | PC13 | GPIO 慢速推挽 | SYS_FAULT_N_MCU | 低=故障；R9默认下拉；只驱动U7逻辑输入，不带LED |
| 3 | PC14 | 不连接 | NC | R6 无测试点，不用 LSE |
| 4 | PC15 | 不连接 | NC | R6 无测试点，不用 LSE |
| 5 | PF0 | HSE | HSE_IN | 24 MHz晶体X1.1 |
| 6 | PF1 | HSE | HSE_OUT_MCU | 经R6到X1.3 |
| 7 | NRST | 复位 | NRST | R4上拉、C10、SW1、J4.5；保持复位功能 |
| 8 | PA0 | ADC1_IN1 | SOA_ADC | U9隔离后1k/33p |
| 9 | PA1 | ADC2_IN2 | SOB_ADC | U9隔离后1k/33p |
| 10 | PA2 | GPIO 推挽 | BRAKE_FORCE_MCU | 经R44到B板；只强制开启制动 |
| 11 | PA3 | GPIO 开漏 | DRV_DRVOFF | R10上拉；释放=关桥，拉低=允许 |
| 12 | PA4 | GPIO 推挽 | ENC_CS_MCU | 经R31；R30上拉；片选由GPIO控制 |
| 13 | PA5 | AF5 SPI1_SCK | ENC_SCK_MCU | 经R32到蓝线 |
| 14 | PA6 | AF5 SPI1_MISO | ENC_MISO_MCU | 绿线经R34 |
| 15 | PA7 | AF5 SPI1_MOSI | ENC_MOSI_MCU | 经R33到黄线 |
| 16 | PB0 | ADC3_IN12 | SOC_ADC | U9隔离后1k/33p |
| 17 | PB1 | ADC1_IN12 | VBUS_ADC | 独立200k/20k分压，换算倍率11 |
| 18 | PB2 | ADC2_IN12 | MOTOR_TEMP_ADC | 10k NTC探头；不是TMP36换算 |
| 19 | VSSA | 电源 | GND | 统一GND，模拟回流就近 |
| 20 | VREF+ | 电源 | 3V3A | C7/C8；关闭VREFBUF输出 |
| 21 | VDDA | 电源 | 3V3A | C5/C6 |
| 22 | PB10 | AF7 USART3_TX | STM_UART_TX | U8 A1输入，向ESP发送 |
| 23 | VSS | 电源 | GND | 地 |
| 24 | VDD | 电源 | 3V3 | C2；MCU共用C9 |
| 25 | PB11 | AF7 USART3_RX | STM_UART_RX | U8 A2Y输出 |
| 26 | PB12 | AF6 TIM1_BKIN | HARD_FAULT_N | 低有效；滤波0；AOE=0 |
| 27 | PB13 | AF6 TIM1_CH1N | PWM_LA_MCU | R21=47Ω，驱动端R27=100k下拉 |
| 28 | PB14 | AF6 TIM1_CH2N | PWM_LB_MCU | R23=47Ω，驱动端R29=100k下拉 |
| 29 | PB15 | AF4 TIM1_CH3N | PWM_LC_MCU | R25=47Ω，驱动端R43=100k下拉 |
| 30 | PA8 | AF6 TIM1_CH1 | PWM_HA_MCU | R20=47Ω，驱动端R26=100k下拉 |
| 31 | PA9 | AF6 TIM1_CH2 | PWM_HB_MCU | R22=47Ω，驱动端R28=100k下拉；禁用UCPD下拉 |
| 32 | PA10 | AF6 TIM1_CH3 | PWM_HC_MCU | R24=47Ω，驱动端R42=100k下拉；禁用UCPD下拉 |
| 33 | PA11 | 外部不连接 | NC | R6 无测试点；TIM1 TRGO2/OC4 在内部触发 ADC |
| 34 | PA12 | GPIO 推挽 | DRV_NSLEEP_MCU | 本版正式使用；R11+R12/C20；默认睡眠 |
| 35 | VSS | 电源 | GND | 地 |
| 36 | VDD | 电源 | 3V3 | C3 |
| 37 | PA13 | SWD | SWDIO | J4.2 |
| 38 | PA14 | SWD | SWCLK | J4.4 |
| 39 | PA15 | AF4 I2C1_SCL | I2C_SCL | 2.2k上拉3V3；与B/C低速器件相连 |
| 40 | PB3 | AF6 SPI3_SCK | DRV_SCK_MCU | R14=22Ω；不再用SWO/JTAG |
| 41 | PB4 | AF6 SPI3_MISO | DRV_SDO | R17=1k上拉；禁用UCPD死电池下拉 |
| 42 | PB5 | AF6 SPI3_MOSI | DRV_SDI_MCU | R15=22Ω |
| 43 | PB6 | GPIO 推挽 | DRV_CS_MCU | R16=22Ω；R18=10k上拉；禁用UCPD下拉 |
| 44 | PB7 | AF4 I2C1_SDA | I2C_SDA | 2.2k上拉3V3 |
| 45 | PB8 | BOOT0/GPIO输入 | BOOT0 | 100k下拉；JP1焊桥临时接3V3 |
| 46 | PB9 | GPIO 推挽 | MOTOR_PWR_EN_MCU | 本版控制B板电机母线使能；R46/R47默认关 |
| 47 | VSS | 电源 | GND | 地 |
| 48 | VDD | 电源 | 3V3 | C4 |

## 3. 必须保留的电气细节

- PA3 为开漏 DRVOFF，外部 10k 上拉；PB12 为低有效 BKIN，保持无滤波、AOE 禁止自动恢复。PA11 的 TIM1_CH4 继续用于 ADC 触发观察。
- nSLEEP 使用原输入的 2.2k 串阻、100k 下拉、100nF；母线使能沿用原输入 R46/R47 默认关断。复位时 GPIO 默认值不能替代板上的外部上下拉。
- PC13 只慢速驱动 U7 的高阻逻辑输入。U7 输入有 100k 下拉，输出开漏上拉到 **3V3_ESP**；STM 自身 3V3 不与屏幕 3V3 并联。
- UART 保留已经选定的 **TXU0202**；不用因 9/18 的概念建议再换购两个单门缓冲。PB10→ESP GPIO44，PB11←ESP GPIO43，5 Mbaud。
- 原厂 AS5048A：黑 GND、红 5V、绿 MISO、黄 MOSI、蓝 CLK、白 CSn。板上 J3 自定义焊盘号不代表厂家插头几何顺序；后续实现使用已存在的 AS5048A 编解码，不另猜型号。
- SO 三相的 ADC 支路经过 TMUX1511；硬件比较器支路不经过该开关。DRV 物理 nFAULT 与汇总 HARD_FAULT_N 经 U6 分开，不直接互相反灌。
- 母线 ADC 使用 100k＋100k / 20k，比较器使用 100k / 20k。不得混用分压节点或倍率。ADC 采样窗口、源阻抗及两颗 1nF 的实际建立时间仍需在实板验证。
- NTC 是 10k 上拉到参考电源域、10k/B3950 到地；公式在现有 **200 Hz** 监测任务运行，ADC 中断只保存原始读数。软件 -40～125 ℃ 为信号合理性窗口，70/85 ℃ 为现有告警/故障阈值；不代表热敏电阻精度、安装温差或故障响应时间已测定。

所有逐器件脚号、66 个测试点、两条 10P FFC 的针序仍见 [已购器件版完整连接说明](../outputs/01a08963-e2d7-71e2-a353-8710a44dc948/stm32-foc-schematic-20260914/GL30_A板_STM32_FOC_原理图连接说明.md)。

## 4. 灯环与普通按键：尚未冻结的部分

PB9 已确定归母线使能，撤销 9/18 的 PB9/TIM17 灯带建议。也不能把 Waveshare 的 J1 GP0/GP1/GP2 当作未占用脚直接接灯带：GP0 涉及启动，GP1 已用于故障，GP2 需保留模组原有电源边界。

PB8 的 TIM16_CH1 在 ST 的该封装数据库中存在，是后续灯带候选；它同时是 BOOT0，必须先审查启动选项字节、焊桥限流、缓冲输入在掉电时的负载和复位波形，再决定是否采用。本轮没有把 PB8 改成输出，也没有把这一候选写进采购/投板结论。

普通按键和低速使能可继续评估 9/18 的 IO 扩展器方案，但型号、供电域、地址、连接器和驱动仍待收敛；TCA9535 不是已购/已接入事实。安全关断与电机使能不依赖 I2C 扩展器。

## 5. 验证和下一步

本轮先通过回归检查复现 PA12、PB9、母线倍率三项旧错误，再修改。NTC 增加开路、短路、合理范围、温度参考点及全 ADC 区间单调性检查。日志和构建结果见 [本轮接口核对包](../outputs/product-interface-20260927/README_CN.md)。

重新生成时还修正了 IOC 的 `ADC12CLockSelection/ADC345CLockSelection` 大小写，移除无效派生字段；选源仍是 PLLP 的 40 MHz，未改动已有生成 C 的 ADC 实际时钟设计。BKIN、死区及禁止自动恢复保留。

原生 [KiCad A 板原理图首版](../hardware/pcb/stm32-foc-a/README_CN.md)已完成：9 页、518 连接端点对照一致、ERC 0 违规；并非可投板结论。产品 AS5048A SPI1 只读端口已接入，见[10/02 记录](../outputs/project-advance-20261002/README_CN.md)。母线请求、唤醒、配置读回、采零与驱动确认已接成[无转矩准备状态机](../outputs/power-startup-review-20261002/README_CN.md)，尚未烧录或实板验收。下一步闭环实物封装、排线/编码器小板、灯环/按键接口，再按合并机械包络布局，保持不布线。零位标定、采样比例、保护注入、ADC 时序、回生、按压/皮带手感属于实物验证，不由离线测试替代。

官方核对入口：[ST STM32G474CE](https://www.st.com/resource/en/datasheet/stm32g474ce.pdf)、[TI DRV8316](https://www.ti.com/lit/ds/symlink/drv8316.pdf)、[TI SN74LVC1G07](https://www.ti.com/lit/ds/symlink/sn74lvc1g07.pdf)、[Waveshare 1.32 原理图](https://files.waveshare.com/wiki/ESP32-S3-Touch-AMOLED-1.32/ESP32-S3-Touch-AMOLED-1.32-Schematic.pdf)。

2026-10-03 补充：R6 的 PC14/PC15/PA11 外部连接为 NC。冻结固件 board_config.h 的 PA11 描述条目仍记 AF11，未在本轮修改；不能把描述条目当作新增走线要求。J4 最新为单排 5P/2.54 mm，NRST 在第 5 脚。历史逐引脚接线文档中的测试点及 2×5 J4 已被 R6 取代。

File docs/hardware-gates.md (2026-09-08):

# V7 硬件闸门

闸门必须顺序通过；失败时保留原始数据并停在当前层，不用更高电压、更大电流或软件滤波掩盖问题。

| 闸门 | 范围 | 放行证据 |
| --- | --- | --- |
| G0 | 厂家资料闭合 | 编码器接口/电压/线序/连接器/速率/校准；安装面/出线/通孔/载荷书面答复 |
| G1 | 原理图/CAD 设计评审 | 公共电路 ERC、保护链、官方 STEP 装配、真实线束包络、独立评审 |
| G2 | 不上电首件 | 阻值、方向、焊接、短路、默认上下拉、连接器、防反灌、机械干涉 |
| G3 | 3.3 V/SWD/保护静态 | 启动电流、时钟、复位、IWDG、无 PWM；过流/过压注入和 BKIN 关断 |
| G4 | 工厂编码器 | 供电/电平安全，角度连续、方向、分辨率、延迟、零位和错误注入 |
| G5 | 低压电机/FOC | 相序、极对数、电角零位，0.2 A 起步，电流环、deadline、回灌和温升 |
| G6 | 旋环机械 | 用户载荷、跳动、摩擦、回差、轴承/耦合、寿命循环和防尘间隙 |
| G7 | 整机 | UI/音频/通信负载、触觉、连续运行、故障注入、热与报告 |

## 当前门状态

- G0：`PARTIAL/HOLD`。实物、官方 STEP/PDF、参数表、性能曲线以及 `AS5048A + SPI`方向已取得；仍缺编码器供电/线序/连接器/校准、安装面功能和允许载荷。
- 电机被动到货检查（手感、三相 R/L、绝缘、已知转速反电势）可以立即做并归档，不需要越过 G4/G5。
- G4 未通过前不向编码器猜测供电、不进入编码器闭环；G5 未通过前不把厂家 2.13 A/7.4 A 写成已验证能力。
- CAD 的概念包络检查可在 G0 前继续，但不能替代 G0/G1。
- PCB、正式机械件和电机带转均不得越过对应 HOLD。

## 2026-09-08 台架续测与产品闸门的区别

- [H25 扩展验收](bench-validation-20260908-haptic25-extended-cn.md)记录 NUCLEO + TI EVM 的受限 ALIGN、IQ、八模式、STOP/失联关断和无出力通信回归。H8 的母线门故障与 H10 的位移资格失败保留为历史，不再称为当前 H25 失败。
- G5 仍仅为台架局部证据：没有外部电流/力矩计量、温升、回灌或外部 nFAULT 整链实测，不能整体勾选通过。
- 产品工程仅同步修正 ADC 时钟并完成独立构建，未烧录验证；`factory_encoder_pending` 仍有效。台架局部通过不能放行产品 G4/G5/G7，更不能代替外部保护链、整机负载、热、回灌和寿命验证。
- 305 mA 电源限流是用户报告、未经仪表核实，且不等同于相电流限制；软件 STOP 不代表外部电源已断开。

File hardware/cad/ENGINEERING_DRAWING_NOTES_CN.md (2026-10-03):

# GL30 当前工程：隐藏按键与试制图说明

> 新增旋环按压、底部至少 24 RGB 与灯光角度标记的要求见[专项方案](../../docs/knob-press-rgb-architecture-cn.md)。本页工图早于该改动；按压载荷、移动间隙及光腔尚未更新，不能直接作为新版加工依据。

状态：`PROTOTYPE_DRAWING_DRAFT`。这是当前工程的修订，不增加版本号；未推送 GitHub。

## 本次交付

- [六页 A3 工图](../../output/pdf/GL30_Current_Prototype_Drawings_CN.pdf)：整机三视、侧键孔位、键帽剖面、收腰旋环帽、轴承袖套、公差与配合条件。已同步当前STEP；不含新底盖的专用制造详图。
- [轻量外观 STEP](out/CONCEPT_FIT_DEFAULTS/V7_CONCEPT_FIT_DEFAULTS_exterior.step)：直接查看现在的造型和隐藏按键。
- [完整装配 STEP](out/CONCEPT_FIT_DEFAULTS/V7_CONCEPT_FIT_DEFAULTS_assembly.step)：保留厂家电机、屏幕实体和内部概念包络。
- [键帽形状样 STL](out/CONCEPT_FIT_DEFAULTS/parts/button_right_1_CONCEPT_ONLY.stl)：四键几何相同；该文件仍在装配坐标中，切片时需调整摆放方向。没有真实开关或回弹结构。
- [图纸几何与来源哈希](out/CONCEPT_FIT_DEFAULTS/drawing_geometry.json)：实际 STEP 的正投影和实体剖切，不是手绘轮廓。

当前可以用于讨论、报价和外形/尺寸试样，不能据此直接制造一台完整可用的力反馈旋钮。所有 `REF` 是参考尺寸，`HOLD` 是必须补设计或实物确认的项目；不适用未注公差。

## 按钮如何融入外壳

保留左右各两个普通功能键、后侧独立电源键。普通键移到侧后方上段，正面无新增按钮；不把经常使用的功能键藏到必须翻起机器才能按到的底部。

普通键改为浅银色胶囊形，与底座同色、同光泽，收在一条浅凹槽内。第一键用一个灰色小点、第二键用两个小点，不印大字、不用发光图标。它是“低可见度、融入壳体”，不是从所有角度完全看不见。实际手指触达、误触和握持方便程度仍需外形样确认。

| 特征 | 当前名义尺寸 / 要求 |
| --- | --- |
| 每个键帽面 | 11.00 × 4.00，圆端 R2.00 |
| 键帽体深 | 2.70；内挡边厚 0.60 |
| 内挡边 | 12.40 × 5.40，圆端 R2.70，只用于向外防脱 |
| 每个导向通孔 | 11.40 × 4.40，圆端 R2.20 |
| 每侧公共浅槽 | 33.00 × 6.60，深 0.60，圆端 R3.30 |
| 键面内收 | 相对壳体侧面 0.30；相对槽底高 0.30 |
| 丝印点 | 直径 0.60；双点中心距 1.30；在键面中心对称 |

坐标单位均为 mm：X 向右、Y 向后、Z 向上；壳体中心 X=Y=0，壳体外底面 Z=0，不含脚垫。壳体前面 Y=-48，后面 Y=+48。每侧两键中心为 Y=20/35、Z=43，即距前端分别 68/83；槽中心 Y=27.5、Z=43。右侧壁 X=48，左侧壁 X=-48；右键面 X=47.7，左键面 X=-47.7。

键帽是有内挡边的单实体，壳体也真实切出了浅槽和通孔。底盖现已可拆，键帽可从内侧装入；按键怎样回弹、PCB怎么固定和整机装配顺序尚未完成，不能把外形模型当成完整按键机构。

## 公差与配合要求

暂按“铝合金旋钮 + 3D 打印壳体/键帽外形样”整理；未获得用户或供应商的材料/工艺确认。6061 只是旋钮形状样的报价候选，不是 BOM 冻结。所有下列目标均指涂层、油墨和去毛刺完成后的成品表面。

1. 键帽长/高、导向孔长/高分别建议 ±0.10。名义居中时单边缝为 0.20；极限为 `(11.30-11.10)/2=0.10` 到 `(11.50-10.90)/2=0.30`。高度方向相同。该计算不含偏心，不能用它代替装配检查。
2. 内挡边各外形尺寸建议 ±0.10。相对孔口居中单边搭接名义 0.50，最小 `(12.30-11.50)/2=0.40`。偏心与装配路径必须另行检查；挡边不是回弹簧，也不是内向过行程限位。
3. 键面内收目标 0.30±0.10 是装配验收值。侧壁厚、内侧接触面、键帽体深共同决定它；不能只凭名义 3.00 和 2.70 保证，先测壳体实际厚度再修配键帽体深。
4. 打印机或供应商若不能保证开口 ±0.10，先做孔/键帽试片，再修配开口。不宣称任意打印机可以直接达到 CNC 公差。装配后检查四周间隙、不卡擦，真实开关装入后再检查回位、触发和过行程。
5. CNC 外形样的自定未注线性公差建议 ±0.10、角度 ±0.5°；不引用未经核实的通用公差等级，不套用到轴承座、配合轴、曲面轮廓精度及其他 HOLD 项。
6. 旋环内孔有效包络 40.00±0.05 与固定盖板外径有效包络 39.00±0.05：同心条件下径向缝 0.45～0.55。若再满足相对轴偏≤0.10，则局部最小缝≥0.35。这里“有效包络”要求计入形状误差；实际轴承偏移、跳动和装配误差不能漏算。该条件链并非实物已达标。
7. 袖套内孔 Ø52.20 仍为 REF/HOLD。它相对名义 Ø52 轴承是径向 0.10 的空间预留，不能保证定心、外圈防滑移或传扭，绝不能直接写成正式 H7 压配。

轴承配合原则参考 [NSK：Getting a good fit](https://www.nsk.com/content/dam/nsk/eu/en_gb/documents/P_TI-0001_EN.pdf)。配合必须结合旋转载荷、薄壁变形和游隙复核；引用厂家原则不等于批准当前设计。

## 工图范围和必须补齐的项目

| 可据当前图进行 | 暂不能据此放行 |
| --- | --- |
| 外观尺寸沟通、报价、打印握持样 | 整机加工、可通电测试样机或承载成品 |
| 侧键位置及开口试片 | 开关型号、PCB、真实行程/按压力、回弹、内向限位 |
| 黑色旋环曲面和表面样板 | 袖套/帽件连接、轴承配合、预紧、轴向保持 |
| 固定盖板与旋环的条件清距链 | 盖板材质/厚度强度、透光与关机一体黑效果 |
| 厂家零件包络、可拆底盖及螺钉座查看 | 产品电机/屏幕安装、有效螺纹深度、线束扫掠、载荷和实际紧固配合 |

`torque_carrier` 与 `fixed_spider` 现各为单实体，但强度与实际安装未验证。旋环帽与袖套尚没有产品级传扭连接。新增底盖89.4×89.4×3，单边名义缝0.30；四孔中心 `(±40,-29)`、`(±40,14)`，Ø3.4通孔和Ø6.7×1.65深90°沉头座，壳体内有对边5.8螺母槽。候选M3×10沉头螺钉+M3螺母，须核对实际头部/配合与载荷。本轮实物联调用另外的[三件式夹具](../../output/models/GL30_MOTOR_FIXTURE/ASSEMBLY_CN.md)，不能混淆用途。完整产品 STEP 不是整机制造完成证明。

## 本次验证证据

- 生成器 56/56 几何检查通过；四个键均为单个有效实体，键面内收 0.3000；新增两支架连通和底盖/包络检查。
- 四键静止及向内移动 0.40 的壳体交集均为 0 mm³；移动后与电池/电子包络交集也为 0。0.40 仅是数字空间检查，不是工作行程，也未验证真实开关。
- 独立读取实际 STEP：外观 22 组件/22 实体、装配 30 组件/438 实体，两份各 35/35 检查通过。新增底盖尺寸/拆卸空间、四处紧固通孔/沉头座/螺母槽；保留真实键槽/孔、槽外侧壁、键帽尺寸/位置/移动空间、颜色及旋环检查。
- 槽边验证使用实际壳体，不假设整条顶面是20到52的直线斜坡：实际为26°斜面接后部水平平台。DeepSeek 对“全长线性斜坡”的越界判断不适用于该模型；已用实际实体边界采样和 STEP 剖投影复核，而非直接采纳其结论。
- 采纳 DeepSeek 的偏心/涂层公差链提醒及轴承 HOLD 建议。它只提供独立复核，不代替本地几何证据。
- 当前外观总包络 96.0000 × 97.2000 × 63.0304；普通侧键不再向外增加总宽。厂家两份原始 STEP 哈希未改变。
- 六页 PDF 由实际 STEP 的正投影/剖切生成，剖切实体有剖面线，尺寸引线采用同一投影坐标；已逐页渲染检查。尺寸数字优先，曲线折线约化容差0.015，不可拿PDF轮廓当加工刀路。
- 未在 SolidWorks 桌面打开测试；未进行实物装配、承载、按键耐久、热、电池或光学测试。

## 如何使用

先看工图第2、3页和按键局部渲染，确认位置/外观。然后用一组孔与键帽做小试片：检查手指是否好按，修配并完成喷涂后再验间隙。最后选实际轻触开关，把 PCB、回弹和限位设计补齐；不要现在就花钱加工整套金属壳体。

沿用已安装的运行时，不需新装软件：

```powershell
.\.venv-cad\Scripts\python.exe hardware\cad\v7_product_model.py
.\.venv-cad\Scripts\python.exe hardware\cad\check_step_exports.py
.\.venv-cad\Scripts\python.exe hardware\cad\export_drawing_geometry.py
& 'C:\Users\foke\.cache\codex-runtimes\codex-primary-runtime\dependencies\python\python.exe' hardware\cad\make_engineering_drawings.py
```

导图前会核对当前 STEP 与回读报告的 SHA-256；旧报告不能用于新图。生成过程覆盖固定文件名，不建立历史版本目录。`tmp/pdf/gl30-drawings` 只是逐页排版检查图，不是另一套项目。

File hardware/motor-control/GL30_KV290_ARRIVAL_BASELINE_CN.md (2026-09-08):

# GL30 工厂编码器版：到货参数基线与首测边界

状态：`REPLACEMENT_SAME_MODEL_CONFIRMED / VENDOR_DEFAULTS / NEW_SAMPLE_NOT_TESTED`

用户已退回之前的电机并重新购买，确认仍为同款 GL30、同绕组/KV、原厂 AS5048A SPI。厂家参数和同款几何继续作为初值；**之前的 200 mA 电阻结果只属于已退样品，不是新电机的测试结果**。新电机不继承旧电机的方向、电角零位或测试通过状态。

本轮按“厂家初值 + 最少必要首测”执行，不重新安排全套参数辨识。当前固件参数已与下面厂家值一致，无须为换同款电机改动 R/L/极对数或放宽保护；本次没有烧录或带电测试。

## 1. 资料闭合情况

| 资料 | 当前证据 | 结论 |
| --- | --- | --- |
| 三维模型 | 用户上传 RAR 内 STEP 的 SHA-256 与仓库现有官方 STEP 完全一致 | 不重复导入，继续使用现有官方 STEP |
| 二维图 | 仓库已有官方 PDF；用户截图与图中关键尺寸一致 | 可用于包络，安装面功能仍待厂家确认 |
| 性能曲线 | 用户提供的厂家图，已归档为 `../cad/vendor/cubemars/GL30_KV290_factory_performance_curve.png` | 仅作供应商声明，未做测功机复现 |
| 编码器型号/接口 | 用户已确认 `AS5048A + SPI`、板上仅芯片和两颗电容，黑 GND / 红 5V / 绿 MISO / 黄 MOSI / 蓝 CLK / 白 CSN | 5 V 标称供电与线序已知；实际电压、SPI 电平/通信、连接器料号仍待验证 |
| 实物 | 用户确认退回原电机、重新购买同款 | 新样品尚无测试记录；只执行第4节最小清单，不把完整参数辨识作为前置条件 |

## 2. 厂家给出的参数

| 类别 | 参数 | 厂家值 |
| --- | --- | ---: |
| 拓扑 | 相数 / 接法 / 极对数 | 3 / star / 7 |
| 额定点 | 电压 / 转矩 / 转速 / 电流 | 12 V / 0.08 N·m / 1990 rpm / 2.13 A |
| 峰值点 | 转矩 / 电流 | 0.28 N·m / 7.4 A |
| 空载 | 转速 | 3060 rpm |
| 常数 | 速度 / 反电势 / 转矩 | 255 rpm/V / 3.73 V/krpm / 0.038 N·m/A |
| 绕组 | 线电阻 / 线电感 | 1.530 ohm / 330 uH |
| 机械 | 转动惯量 / 重量 | 24.2 g·cm² / 41 g |
| 时间常数 | 电气 / 机电 | 0.22 ms / 2.56 ms |
| 环境 | 温度 / 绝缘等级 | -20–50 °C / H |
| 绝缘 | 耐压 / 电阻 | 500 V, 5 mA, 2 s / 500 V, 10 Mohm |

机械图给出：外径 `34.5 ±0.1 mm`、轴向总长 `28.2 mm`、中心孔 `Ø6 ±0.05 mm`；一面为 `3×M3`、深 `3.5 mm`、`Ø20` 分布圆，另一面为 `4×M3`、深 `2.5 mm`、`Ø20` 分布圆。

## 3. 参数一致性与固件采用值

### 3.1 可直接互相校验的项目

- `3060 rpm / 12 V = 255 rpm/V`，所以表中的 255 rpm/V 与空载点完全一致。
- `0.08 N·m / 2.13 A = 0.03756 N·m/A`。
- `0.28 N·m / 7.4 A = 0.03784 N·m/A`。
- 两个转矩点都支持把 `Kt=0.038 N·m/A`作为首轮估算值。
- 若 `1.530 ohm / 330 uH`均为星形电机的线—线测量值，则 FOC 相值初始换算为：

  ```text
  Rphase = 1.530 / 2 = 0.765 ohm
  Lphase = 330 / 2 = 165 uH
  tau_e  = 165 uH / 0.765 ohm = 0.216 ms
  ```

  与厂家 `0.22 ms`一致。

### 3.2 不能写成已验证事实的项目

- 曲线标题为 `KV290@12VDC`，但 290 rpm/V 对应约 3480 rpm；当前基线与固件采用 `255 rpm/V` 一致，不把 `KV290` 当作实测 Ke 前置门槛，先在 EVM 上用低电流闭环逐步验证。
- `1000 / 255 = 3.92 V/krpm`，与表中 `3.73 V/krpm`相差约 4.9%。相/线、峰值/RMS 和驱动定义尚未对齐，不把此换算当作厂家参数错误。Ke 测量可在后续速度/电压模型需要时进行，不阻塞当前低速电流闭环。
- 厂家 7.4 A 点接近堵转端；即使驱动器标称 8 A peak，也没有证明电机、PCB、连接器、电源或散热能持续承受。

### 3.3 当前固件保护与首测边界

| 项目 | 当前值 | 对应含义 |
| --- | ---: | --- |
| PWM / 电流采样 | EVM 20 kHz，同步；产品工程仍为 40 kHz | 两个硬件端口各用对应参数，不能混用 |
| 电流环基线 | `Id = 0.10 A`（校准/对齐参考） | 单位时间低扭矩闭环的起始工作点 |
| q 轴输出 | `abs(Iq) <= 0.10 A`，每次输出 <= 2 s | 与 `B1` 长按与 KEEPALIVE <100 ms 规则绑定；电压矢量上限 0.30 V |
| 电压矢量上限 | `0.30 V` | 与母线变化无关的 FOC 幅值保护 |
| 软件硬限流 | 1.75 A | 当前不作首测执行，列为产品演进目标/验证后放行条件 |
| 用户转矩上限 | 0.060 N·m | 与 `1.6 A` 上限口径一致，为产品目标（非当前首测） |
| 自驱动转矩上限 | 0.015 N·m | 与 0.395 A 对齐，降低空转甩手风险 |

厂商 `2.13 A / 0.08 N·m`和 `7.4 A / 0.28 N·m`保留为待验证能力，不自动转入当前保护边界。

## 4. 替换电机的最小首测清单

| 顺序 | 保留的检查 | 判据与范围 |
| --- | --- | --- |
| 1 断电标记/初筛 | 三根相线固定标为 A/B/C，照片记录；缓慢手转；万用表看 AB、BC、CA 导通且阻值接近、相线与壳体无明显低阻 | 三相与驱动板断开后测量。星形三相互相导通是正常现象，不是短路证据；普通万用表仅排查开路/严重不平衡/碰壳，不宣称完成精密电阻或高压绝缘检测 |
| 2 编码器 | 只给控制器/编码器上电，功率关闭，慢转一圈读角度和诊断 | 方向一致、无异常跳变；0/16383回绕正常，静止允许少量噪声。无须测完整线性、偏心或重装磁钢；新线束端点仍需核对 |
| 3 台架准备/对齐 | 沿用 NUCLEO/TI 手册，先无电机三相执行 PREPARE 验证驱动/采样，再断电接电机，重新 PREPARE → ALIGN | 电流零点与驱动健康通过；本台电机重新识别方向和 RAM 电角零位；厂家通用参数不能替代该对齐 |
| 4 短脉冲/停止 | 初次不装握环，可靠固定定子；先 +50 mA/200 ms，再单独 -50 mA/200 ms；检查停止、B1释放和许可超时保护 | 实际电流/方向与指令可解释、无异常振荡/发热、结束和故障后确实关闭输出。每次准备/接线以当前联调手册为准 |

第一步无需强制四线法或再次200 mA精测，R参数继续用厂家1.53 Ω。若普通万用表读数明显不一致，先排除表笔/接触电阻，再仅对异常项复测；不用百分比门槛去验收未补偿的低阻档读数。

如果选择沿用熟悉的200 mA方法，只记录 **AB、BC、CA** 各一次稳态电压即可，按厂家值预计约0.306 V，三次的另一根相线保持悬空。它是可选的低阻复核，不必再做另一套电阻实验；线阻不决定相序。相线A/B/C是本项目标记，不需要预先查出厂家“真正的UVW”。相线接到输出后的对应关系固定记录，任何换线都断电并重做ALIGN。

现在不测：电感、反电势/定速拖动、Kt/完整扭矩曲线、额定/峰值堵转、编码器全角线性、磁场气隙/偏心、500 V耐压。不买LCR表或测功机，不拆原厂编码器，不写OTP。出现异常时才针对原因补测；电流零点、方向/电角对齐和实际关断不能省。

这四组是进入**低电流FOC联调**的检查，不是连续工作、额定性能或成品安全验收。完整执行顺序见[NUCLEO/TI首测手册](../../firmware-stm32/bench/NUCLEO_G474RE_FOC/README_CN.md)。

### 4.1 已退样品记录（2026-09-01，不适用于替换电机）

用户报告以 `0.200 A` 直流电流依次测得三组线—线端电压 `0.3069 V / 0.3090 V / 0.3099 V`。当前未提供线色/相名、电流源精度和四线接法说明，因此先以 1/2/3 号线对记录，不把它写成温度修正后的标定值。

| 线对 | 端电压 | 按 `R=V/0.200 A` 换算 |
| --- | ---: | ---: |
| 1 | 0.3069 V | 1.5345 ohm |
| 2 | 0.3090 V | 1.5450 ohm |
| 3 | 0.3099 V | 1.5495 ohm |
| 平均 | 0.3086 V | 1.5430 ohm |

- 最大—最小极差为 `0.0150 ohm`，相对平均值约 `0.97%`，明显小于当前 `<5%` 初筛门槛。
- 平均值比厂家 `1.530 ohm` 高约 `0.85%`；在尚未温度修正和校验实际电流前，不构成参数冲突。
- 若仅按本次均值折算，等效相电阻约 `0.7715 ohm`；与固件当前 `0.765 ohm` 初值只差约 `0.85%`，不足以单独触发 PI 修改。
- 原样品结论为 `PASS_INITIAL_RESISTANCE_SYMMETRY / RETIRED_SAMPLE`。它只证明已退电机在当时条件下三组直流线阻对称，不能给替换电机判定通过，也不证明其他参数或功率级。
- 当前线电感状态保留为 `VENDOR_DEFAULT_330_UH / NOT_MEASURED`；厂家线阻、线感和 `0.22 ms` 电气时间常数互相自洽，因此允许在现有低带宽、低电流边界下延期测量。

## 5. 首测与产品演进门槛（不再混淆）

### 5.1 当前 EVM 首测（NUCLEO + TI DRV8316REVM）

| 阶段 | 母线/限流 | 电流命令 | 必须记录 |
| --- | --- | --- | --- |
| 校准/对齐 | 12 V 台源，限流 0.20 A 起 | 固件当前 `Id = 0.10 A`，约 5.5 s；不在该步骤自行升流 | 相电流方向、编码器角度、电角零位重复性 |
| 首次闭环脉冲 | 12 V，台源限流保持 0.20 A | `Iq = ±0.10 A`，单次 ≤2 s，B1 长按 + KEEPALIVE | 跟踪、噪声、失步、母线波形、fault 码 |
| 停止/故障 | 保持当前低功率配置 | 松开 B1、停止 KEEPALIVE、STOP 及错误帧时检查输出关断；不得自动恢复出力 | 实际功率关断、故障锁存、重新校准要求 |

### 5.2 产品后续目标（当前不作为首测步骤）

- 低压边界、较高电流和更高带宽另立实测计划，当前不安排自动升流步骤。
- 1.6 A 及 1.75 A 限流区间作为产品级闭环后续验证边界，需在 EVM + 实测热/故障闭环通过后再进入。

任一阶段发生编码器跳变、电流极性错误、持续振荡、相间不平衡、母线超过钳位阈值或异常升温，立即回到上一闸门；不得同时修改相序、方向、电角零位和 PI。

## 6. 仍需厂家补齐

- AS5048A 模块实际 5 V 电源与逻辑电平、连接器准确型号/对插件号、以及厂商校准/延迟等细节；电气与通信可直接实测，不能把所有厂家回复都作为低电流首测的等待条件。不写 OTP。
- 角度更新率、延迟、错误行为、工厂校准、机械零位与电角零位关系。
- 3-M3/4-M3 两面的定子/转子功能、推荐紧固扭矩、出线弯折包络。
- Ø6 通孔的允许用途、径向/轴向载荷、倾覆力矩和轴承寿命。
- `KV290` 标题与 255 rpm/V 参数表为何不一致，以及 7.4 A 峰值允许时长/占空比/温升条件。

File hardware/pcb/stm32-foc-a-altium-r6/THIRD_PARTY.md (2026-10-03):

# Native schematic symbol provenance

These Altium sheets are derived from the project's reviewed KiCad A01-A07 circuit sheets. The conversion preserves circuit symbols, pin numbers, electrical types and connections; it excludes the test-point sheet and its 66 parts. Three otherwise isolated U1 pins are explicitly unused after test-point removal.

Resistor, capacitor, polarized capacitor, TVS and crystal symbol geometry originates from the official KiCad 10.0.6 libraries. This adapted library material remains under CC BY-SA 4.0 with the KiCad electronic-design exception; see the included `KICAD_LIBRARY_LICENSE.md` and https://www.kicad.org/libraries/license/. The conversion changes the storage format and placement/text representation for native Altium schematic objects. No KiCad footprint geometry is included in this AD package.

Custom IC and interface symbols originate from the GL30 project, drawn from the reviewed component pin tables and manufacturer documents. Datasheet URLs are embedded as symbol parameters. All three paired DRV8316 output pins are separate physical pins in the AD files. A schematic symbol is not a manufacturer-qualified PCB land pattern.

Native file generation uses the existing local `altium-monkey` package, version 2026.8.21; that package's implementation is not redistributed. Altium Designer 26.10.1.5 was used to read the final sheets and independently extract compiled pin/net connections. No OSHWHub board design or third-party SmartKnob implementation was copied.

## User-provided PCB libraries

The user explicitly requested reuse of `G:\dontdel\AD\_Lib` and `G:\dontdel\AD_Lib`. The `User_*.PcbLib` files accompanying this private project are byte-identical copies of the actually referenced user-provided libraries. Source paths, SHA-256 hashes, footprint names and per-reference matching evidence are recorded in `user_footprint_mapping.json` and `verification/user_library_link_check.json`. Original library files were not modified. No separate license to publish or redistribute those user-supplied libraries is asserted.

The linked PCB models do not change schematic pin functions, purchased component part numbers, or fitted/DNP status. Generic package reuse is distinguished from exact manufacturer-part matches in `USER_LIBRARY_CN.md`. The existing library symbols are used as matching evidence; their unrelated part-number parameters and inaccurate datasheet hyperlinks are not copied into the schematic.

## R5 project derivative

`GL30_Adjusted_User.PcbLib` contains one footprint derived from the user-supplied SamacSys B2B-PH-K-S footprint. Only the name, description, plated-hole diameter (0.85 mm), and copper pad size (1.40 mm) were adjusted. Source libraries are unchanged; embedded 3D payloads are preserved. This project copy retains the source library licensing conditions.

## R6 J4 project derivative

`GL30_J4_Header.PcbLib` derives one footprint from the user-supplied `STM32F407_Ctrl.PcbLib` / `HDR2.54-LI-5P`. Only the footprint name, description and plated-hole diameter (1.02 mm) were adjusted. The 1.70 mm lands, pad numbers, positions, shapes and embedded 3D payloads are preserved. The original library is unchanged; source licensing conditions remain applicable.

## Public snapshot distribution

The public Git snapshot intentionally omits all five user-supplied or derived PcbLib files. The original local project is unchanged. The document-list-only change in the public PrjPcb is documented in README_CN.md; embedded native schematic model links are retained. No additional redistribution rights for personal libraries are claimed.

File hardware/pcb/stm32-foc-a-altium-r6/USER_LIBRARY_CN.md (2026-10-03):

# 用户补库核对与接入 R6

2026-09-27；版本 `A-SCH-AD-R6-USER-LIB-NO-TP`。已关联 **142/146 个位号**，较 R4 增加 10 个；按用户决定将 J4 改为单排 5P、2.54 mm。其余 145 个位号的采购料号、数值、封装规格与装配状态保持不变。

## 本次新增

| 位号 | 已购料号 | 核对结果 |
| --- | --- | --- |
| U1 | STM32G474CET6 | 精确料号对应 LQFP48；48 焊盘、0.5 mm 脚距及编号核对通过 |
| C28、C29、C53、C54 | 35SVPF39M | 精确符号关联共用封装 `16SVF270M`；E7 焊盘尺寸与极性一致 |
| SW1 | SKRPASE010 | 焊盘尺寸一致；1/2 常连、3/4 常连，与 NRST/GND 分组一致 |
| J5、J6 | FH12-10S-0.5SH(55) | 10 个信号焊盘和 2 个固定焊盘核对通过；11/12 仅为机械固定焊盘 |
| J7 | B2B-PH-K-S(LF)(SN) | 原库孔径 0.70 mm；项目派生封装改为 0.85 mm 孔、1.40 mm 焊盘 |
| J4 | 通用 1×5P 2.54 mm 直插排针 | 用户库 HDR2.54-LI-5P 派生；孔改 1.02 mm，保留 1.70 mm 焊盘 |

电容封装名称 `16SVF270M` 是库里的共用名称，采购料号仍为 **35SVPF39M、39 µF/35 V**。其两焊盘内间距 2.8 mm、外侧总跨度 11.1 mm、焊盘宽 1.9 mm，与松下 E7 推荐值一致，1 为正极、2 为负极。库中 3D 投影包含底座和端子，不能将该平面包络与圆柱直径、器件高度混作同一尺寸。[松下推荐焊盘](https://industrial.panasonic.com/cdbs/www-data/pdf/AAB8000/AAB8000COL10.pdf)

J7 原库的 0.70 mm 孔偏紧。JST 对两针 PH 插座在玻纤基镀通孔板上的建议成品孔径为 0.80–0.85 mm，因此本工程采用 0.85 mm；焊盘扩大到 1.40 mm，最小环宽为 0.275 mm，保持 2 mm 脚距。修正只存在于 `GL30_Adjusted_User.PcbLib` 中，原库未改。原引脚编号、位置、外形和嵌入的 3D 模型数据保持一致。[JST 官方孔径说明](https://www.jst.com/resources/faq/)

STM32 的用户库焊盘长为 1.475 mm，ST 示例为 1.20 mm；脚距、宽度和编号一致，本轮保留用户库的较长焊盘。FFC 的全部焊盘还与工程已有的 KiCad FH12 封装逐一比对，坐标原点换算后位置和尺寸一致。PCB 阶段保留 11/12 固定焊盘且不自动连接信号网；实际排线仍须确认触点朝向并逐根测通。[ST 图纸第 206–208 页](https://www.st.com/resource/en/datasheet/stm32g474ce.pdf)，[Hirose FH12](https://www.hirose.com/en/product/p/CL0586-0522-3-55)，[ALPS SKRP 图纸第 2 页](https://tech.alpsalpine.com/cms.media/product_catalog_ta_02_skrp_en_2cd80f610b.pdf)

## J4 用户确认后的更改

采用普通单排 5P、2.54 mm 直插公排针。引脚：**1=3V3/VTREF，2=SWDIO，3=GND，4=SWCLK，5=NRST**。VTREF 只接调试器目标电压检测端，不能接 5 V 或调试器电源输出端。1 脚是方形焊盘，按本版编号接线。

原用户封装孔径 0.90 mm 对常见 0.64 mm 方针余量较小，因此在 `GL30_J4_Header.PcbLib` 中将孔径改为 1.02 mm。原 2.54 mm 脚距、1.70 mm 焊盘、编号、外形及嵌入 3D 数据保留；没有修改用户源库。[Samtec 标准方针孔径参考](https://suddendocs.samtec.com/catalog_english/tsw_th.pdf)，不要求采购这个品牌。

修改只涉及 J4 的符号、连接、规格和封装；其余原生对象及采购器件保留。AD 实际读出的 J4 已无 6–10 脚，五个信号与上表逐一一致。详见 `verification/j4_change_r6.json`。

## 全部已关联封装

| 工程库 | 封装名称 | 位号数 |
| --- | --- | --- |
| `GL30_Adjusted_User.PcbLib` | `GL30_B2B_PH_K_S_FR4_D085` | 1 |
| `GL30_J4_Header.PcbLib` | `GL30_HDR_1X05_P254_D102` | 1 |
| `User_LCSC.PcbLib` | `C151256_DO-214AA` | 1 |
| `User_LCSC.PcbLib` | `C181596_TSSOP-14` | 2 |
| `User_LCSC.PcbLib` | `C5218861_VQFN-40_5x7` | 1 |
| `User_STM32F407_Ctrl.PcbLib` | `C0603_M` | 43 |
| `User_STM32F407_Ctrl.PcbLib` | `C0805_M` | 6 |
| `User_STM32F407_Ctrl.PcbLib` | `R0603_M` | 70 |
| `User_STM32F407_Ctrl.PcbLib` | `R0805_M` | 1 |
| `User_STM32F407_Ctrl.PcbLib` | `XTAL-3225-4P` | 1 |
| `User_SamacSys.PcbLib` | `16SVF270M` | 4 |
| `User_SamacSys.PcbLib` | `CAPC3225X270N` | 1 |
| `User_SamacSys.PcbLib` | `FH1210S05SH55` | 2 |
| `User_SamacSys.PcbLib` | `QFP50P900X900X160-48N` | 1 |
| `User_SamacSys.PcbLib` | `RESC3116X65N` | 1 |
| `User_SamacSys.PcbLib` | `SKRPASE010` | 1 |
| `User_SamacSys.PcbLib` | `SOP50P310X90-8N` | 1 |
| `User_SamacSys.PcbLib` | `SOP65P640X120-14N` | 1 |
| `User_SamacSys.PcbLib` | `SOT95P280X145-5N` | 3 |

逐位号对应关系与来源见 `BOM_no_testpoints.csv`、`user_footprint_mapping.json`。三份 `User_*.PcbLib` 与当前用户原库逐字节相同；`GL30_Adjusted_User.PcbLib` 与 `GL30_J4_Header.PcbLib` 是明确标注的项目派生库。

## 仍需确定

| 位号 | 当前定义 | 需要完成的内容 |
| --- | --- | --- |
| J1 | 母线直焊接口，2 焊盘 | 按导线与板形确定孔径、间距及应力释放 |
| J2 | 电机三相直焊接口，3 焊盘 | 按电机原线和板形确定焊接结构 |
| J3 | 编码器直焊接口，6 焊盘 | 按实际线束及空间确定排布并标清编号 |
| JP1 | 默认断开的两焊盘焊桥 | 随 PCB 设计补入，不需要采购器件 |

J1/J2/J3 的不装配标记表示直接焊线，PCB 焊盘必须保留。C53/C54 仍为可选不装配电容。

## 实际验证

- 本机 AD 26.10.1.5 实际识别 142 个位号的封装，包含 J4/J7 修正版。
- 7 页、146 个位号、447 个连接引脚、9 个明确未连接引脚、98 个网络与设计输入及用户确认的 J4 更改一致；测试点为 0。
- AD 报告 **0 错误、34 条警告**：4 个上述板上焊盘封装缺项、30 个无驱动源提示。没有关闭检查规则。
- `DM_Compile` 返回 0；本轮连接提取与逐引脚比对通过，不代表所有编译检查通过或投板放行。
- J7 派生封装经保存回读验证：镀通孔、孔径、焊盘尺寸正确；其他图元几何和嵌入 3D 数据一致。
- 封装关联前后，7 页图面完全一致。没有 PCB 布局、布线或硬件上电验证。

最终证据见 `verification/ad_acceptance.json`、`verification/connectivity.json`、`verification/added_library_review_r5.json` 、`verification/j7_derivative_check.json` 和 `verification/j4_change_r6.json`。

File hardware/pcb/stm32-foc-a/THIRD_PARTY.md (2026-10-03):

# Library provenance

The project-local `GL30.kicad_sym` contains GL30 custom symbols and copies of the official KiCad symbols R, C, C_Polarized, D_TVS, Crystal_GND24, PWR_FLAG and TestPoint. Selected official KiCad footprints are copied into `GL30.pretty`.

Official library source: KiCad 10.0.6 Windows distribution, signed by KiCad Services Corporation; downloaded from the Tsinghua mirror listed by the official KiCad Windows download page. Maintainers: the KiCad library community. See https://www.kicad.org/libraries/license/ and the included `KICAD_LIBRARY_LICENSE.md`.

The redistributed library material remains under CC BY-SA 4.0 with the KiCad electronic-design exception. Project symbols are renamed into the GL30 namespace. The copied footprints retain their original pad geometry; external 3D-model links were removed so opening the schematic does not require a separate 3D-model download. Embedded symbols have been flattened where necessary. `generation_manifest.json` records original footprint paths and hashes.

Custom IC symbols were drawn from the component pin table and checked against manufacturer documents; component datasheet URLs are embedded in the schematic. U2 uses KiCad 10 stacked pin numbers for duplicated phase-output pads. A symbol is not a manufacturer-qualified land pattern.

No OSHWHub project files or SmartKnob implementation code were copied into this schematic. Those projects are comparison references listed in `开源项目对照.md`.

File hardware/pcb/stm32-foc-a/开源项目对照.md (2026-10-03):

# OSHWHub 同类项目与 GL30 的适用关系

核对日期：2026-09-27。下面“已验证”均是作者对其指定硬件/版本的说明，不继承为 GL30 实板验证。

| 项目 | 已公开的内容 | 对 GL30 的用途与差异 |
| --- | --- | --- |
| [SmartKnob 原版的立创版本](https://oshwhub.com/eda_ouqnklkk/smartknob-original) | 作者说明 view_base_1 / 官方 0.4 已验证；提供 base/screen、固件和适配结构附件，并列出原始 KiCad 来源 | 最接近旋钮的完整产品形态：可配置档位/止挡、圆屏和按压反馈。原版以 ESP32、TMC6300、小云台电机和中空穿线为基础；不能直接替代 GL30 实心轴＋同步带、G474＋DRV8316、466×466 AMOLED 的已购硬件 |
| [AxDrive-L：STM32G4 FOC 学习板](https://oshwhub.com/lylssy/foc_driver) | 作者提供原理图、硬件设计报告和 [代码仓库](https://github.com/disnox/AxDr_L)，包含供电、保护与编码器接口说明 | 适合学习 MCU、供电和测试接口的组织。其 BOOT0/CAN 复用、电流取样阻值、母线分压需按自身版本理解；不能照抄为 G474CET6 的物理脚号和 DRV8316 电流增益 |
| [STM32G431 有感 FOC 驱动板](https://oshwhub.com/al_user/esc_new) | 作者报告电流环、速度环已调通；采用 FD6288Q、分立 MOS、INA199、TLV9062 等 | 可比较紧急关断、调参、波形接口和模拟电路分区；驱动及采样架构与本项目不同，不沿用其增益、MOS 驱动参数和保护阈值 |

判断：有类似项目，也值得用；其中 SmartKnob 最接近产品形态，后两者对 FOC 板设计更有参考价值。目前检索没有找到可确认与“STM32G474CET6＋DRV8316RRGFR＋原厂 AS5048A”完全一致并适配现有机械的整板。本次没有下载并逐线审核 OSHWHub 在线 EDA 工程，因此不声称已完成第三方整板审核或一键转换。

GL30 本轮保留已购器件，主要元件脚号、Buck/充电泵、掉电隔离和故障电平仍直接对照 ST、TI、ams/Infineon 原厂资料。SmartKnob 的来源可继续沿 [原始仓库](https://github.com/scottbez1/smartknob) 查看，其中有原生 KiCad 硬件；应区分作者发布的已测试版本和自动生成的未测试产物。

本次未复制第三方工程或改变 GL30 许可。若后续复用其文件/代码，应按对应版本的开源许可保留来源与必要声明。

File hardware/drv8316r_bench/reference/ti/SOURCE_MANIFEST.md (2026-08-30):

# TI official reference manifest

The public repository keeps only this source manifest. Vendor PDF files are downloaded locally from TI and remain ignored; a source file is reference evidence, not proof that TI reviewed this board or that an official EVM was physically tested.

| Expected local file | Official source | SHA-256 of reviewed copy | Purpose |
| --- | --- | --- | --- |
| `DRV8316_Datasheet_SLVSF16B.pdf` | <https://www.ti.com/lit/ds/symlink/drv8316.pdf> | `39F1977BF713D0697B12967D818C2150BFB697A80FD34BAF4A13E322CB50C6B0` | Pinout, ratings, external components, registers, protection and layout guidance |
| `DRV8316REVM_User_Guide_SLVUBZ9.pdf` | <https://www.ti.com/lit/pdf/SLVUBZ9> | `E96B6659C6E0110D4515BD0A0A15DB56AD13F7055A3DD287ECF2D383C33EF366` | Official EVM interface, protection, test-point and schematic reference |
| `TLV1704_Datasheet_SBOS589.pdf` | <https://www.ti.com/lit/ds/symlink/tlv1704.pdf> | `B971C8CA9AE7DA43D67FA3486F202E6E688D8F5CC4B220268473FC0B4904C42B` | Supply range, input/output behavior and comparator timing |

The TI hardware-source package `SLOC372A` is not part of this repository and this validation board must not be described as a copy of the official EVM PCB. Contributors may download vendor material under its original terms for local comparison, but should not commit it without confirmed redistribution permission.

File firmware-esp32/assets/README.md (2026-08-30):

# Assets

只存当前 AMOLED 字体、图标和经过许可的资源；生成文件必须可追溯到源资源和脚本。

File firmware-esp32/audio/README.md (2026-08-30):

# Audio

UI 提示音归本模块；电机绕组发声属于实验功能，默认与正常触觉互斥。

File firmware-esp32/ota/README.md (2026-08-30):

# OTA

后置模块。只有有线烧录、回滚和版本能力帧完成后再实现，不作为首板启动依赖。

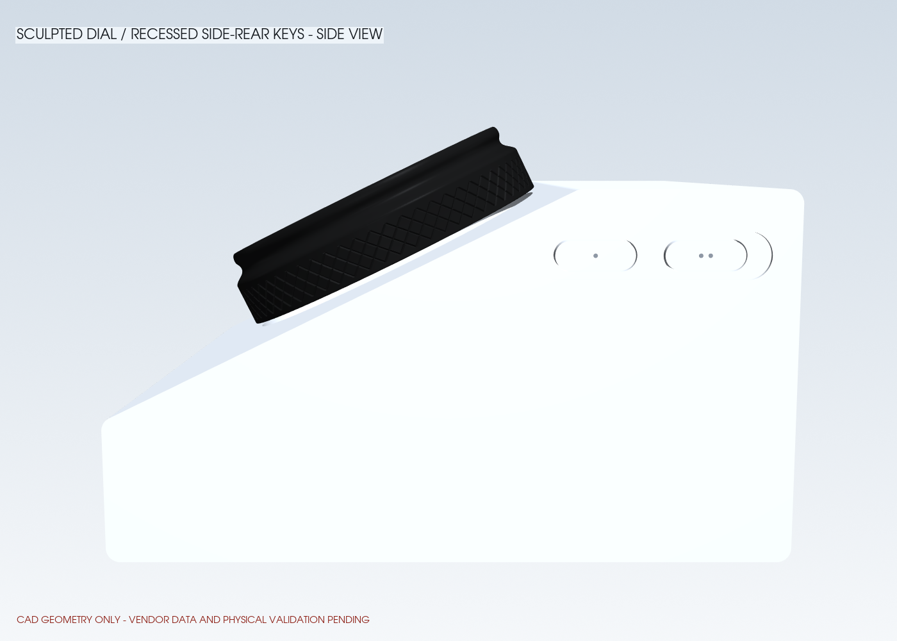
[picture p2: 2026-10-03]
hardware/cad/out/CONCEPT_FIT_DEFAULTS/V7_CONCEPT_FIT_DEFAULTS_side.png

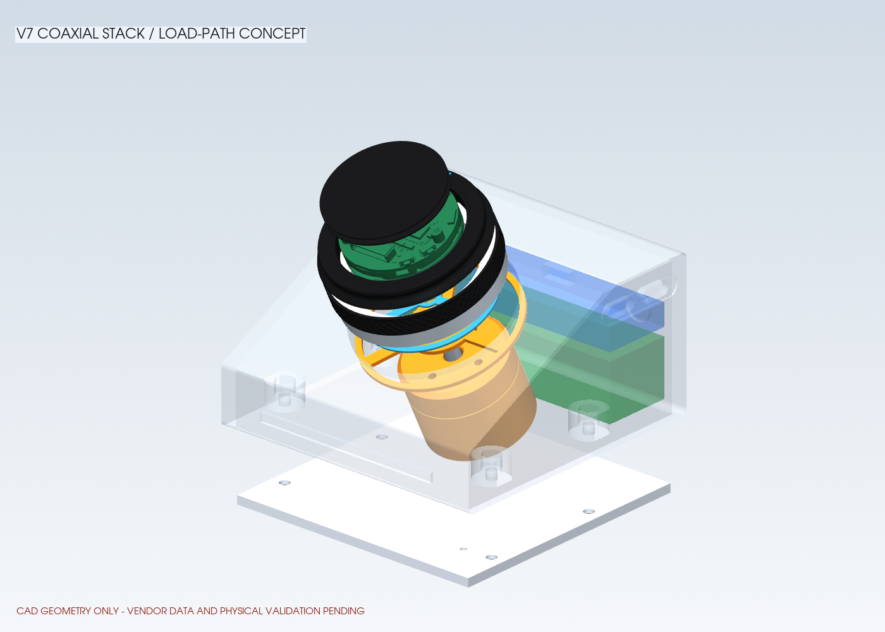
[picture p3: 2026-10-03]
hardware/cad/out/CONCEPT_FIT_DEFAULTS/V7_CONCEPT_FIT_DEFAULTS_exploded.png

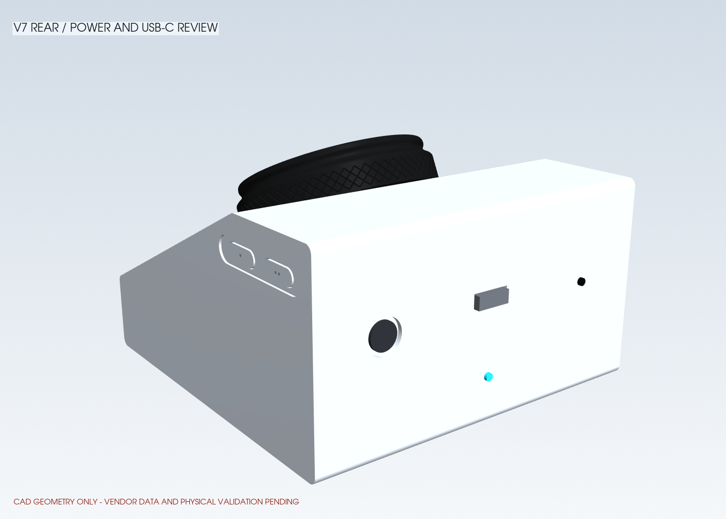
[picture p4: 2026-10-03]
hardware/cad/out/CONCEPT_FIT_DEFAULTS/V7_CONCEPT_FIT_DEFAULTS_rear.png

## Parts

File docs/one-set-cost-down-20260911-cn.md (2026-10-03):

# GL30 单套采购降本与隐藏屏幕方案

更新：2026-09-11。用户只制作一套，电子器件和接头合并为一张表，贵芯片不备料；取消外露的屏幕支架。

最新整机模型已改为 [R4 完整内部布置](full-assembly-r4-20260911-cn.md)：补齐 PCB、电池、七开关和安装空间；下文 R3 只保留为此前核心研究记录。

## 本次采购文件

[单套降本 BOM（XLSX）](../outputs/01a08963-e2d7-71e2-a353-8710a44dc948/bom-cost-down/GL30_单套降本BOM_20260911.xlsx) 包含 79 行、1 个 sheet。R4 将电池目标改为 74×24×21 mm，并补上待选扬声器及插头线，贵芯片数量和已填价合计不变。名称、完整型号、封装、装机/备用/已有/购买数量均单列；可筛选。原用户附件保持不变。

| 金额口径 | 人民币元 | 说明 |
| --- | ---: | --- |
| 原附件已填价明细合计 | 2394.80 | 原表总计手填 2394，少算 0.80 |
| 仅减少采购数量、沿用原型号 | 750.40 | 用于区分数量减少和型号替代的影响 |
| 本轮已填价项目＋替代电感预算 | 593.40 | 包含三只电感合计 30 元的预算 |
| 相对原采购量的预算减少 | 1801.40 | 数量减少 1644.40；电感替代再预留节省 157 |

**593.40 元不是整机到手总价。** 还有 17 个需要采购而缺价格的行，包括屏幕模组、待选扬声器、分流电阻、连接器/线材及定制电池；PCB加工、焊接、机械件与运费也未计入。除两个替代电感外，单价沿用用户附件，未宣称已重新获得实时成交价。表中 K 列可填新报价，R 列保存原单价，新报价不会改写历史成本。

## 已选定的国产电感

| 编号/用途 | 原型号、原单价 | 本轮选型 | 购买 | 外形（名义长×宽×高） | 预算 |
| --- | --- | --- | ---: | --- | ---: |
| B04，BQ25798 充电电感 | XAL5030-102MEC，47 元 | 顺络 MWSA0603S-1R0MT，1 µH ±20% | 1 只 | 6.6×7.0×2.8 mm，高度上限 3.0 mm | 10 元 |
| B09，两路 5 V 降压 | XAL6060-103MEC，70 元 | 顺络 MWSA0804S-100MT，10 µH ±20% | 2 只 | 8.2×8.8×3.8 mm，高度上限 4.0 mm | 20 元 |

两款都是本次首板候选选型，**不是原焊盘直接替换料**。需要按顺络推荐焊盘修改 B 板。1 µH 型号 DCR 上限 7.4 mΩ、典型饱和电流 15 A、典型温升电流 12 A；10 µH 型号分别为 59 mΩ、8 A、6.5 A。数据表以约 30% 感量下降定义饱和，以约 40℃ 温升描述温升电流；这些不是整机允许连续电流。数据表同时列出较低电流数值，表头写作 Max./Typ.，本记录不将较低列擅自改称“保证最小值”。依据：[顺络 MWSA-S 原厂规格书，尺寸表与电气表](https://www.alfatec.de/fileadmin/productfiles/datasheets/sunlord_mwsa_s_series.pdf)。

选择依据和实际限制：

- BQ25798 的 1 µH 必须搭配 1.5 MHz；不能仅为便宜改成 2.2 µH 而保持原开关频率。饱和电流需覆盖输入/充电/放电/OTG各工况平均电流加半个纹波，本轮只沿用原项目正向充电路径，没有添加 OTG 工况或提高充电电流。[TI BQ25798 Rev.C，8.2.2.2](https://www.ti.com/lit/ds/symlink/bq25798.pdf?ts=1741488182166)
- LMR33630 高侧限流最大值为 5.05 A；TI 建议电感饱和额定覆盖该限流值。本轮没有选只标“10 µH / 2–3 A”的小电感。0804 的典型电流数据具备候选裕量，仍须检查温度降额、批次曲线和实测峰值。[TI LMR33630，7.5 与 9.2.2.4](https://www.ti.com/lit/ds/symlink/lmr33630.pdf)
- 以 15 V 输入、5 V/3 A 输出、初始感量下偏至 8 µH、开关频率下限 340 kHz 筛查，纹波约 1.225 A，峰值约 3.613 A。这个计算没有纳入感量随温度/偏流变化，不是最坏条件实测保证。[本轮计算记录](../outputs/01a08963-e2d7-71e2-a353-8710a44dc948/bom-cost-down/substitution-review.json)
- 10 µH 替代件的直流电阻高于原件，不能宣传效率完全相同。仅用 3 A 直流与冷态 DCR 上限估算，铜损为 `3²×0.059 ≈ 0.531 W/只`；还没有包括热态电阻、交流纹波与磁芯损耗。首板需检验负载阶跃、输出纹波、启动/限流、温升，并核对封闭外壳的最坏工况。

价格证据：1 µH 在 [DigiKey 单只 Cut Tape 页面](https://www.digikey.com/en/products/detail/shenzhen-sunlord-electronics-co-ltd/MWSA0603S-1R0MT/14119928) 显示参考 US$0.98；这不是国内人民币含运报价。10 µH 在 [立创 C17700171](https://item.szlcsc.com/18830083.html) 可核对完整型号，但本轮未取得国内拆零成交价。B04/B09 均按 **10 元/只作预算预留**，不据此声明已省下现金。拆零/MOQ须按选定采购渠道确认；不要为了凑整盘增加采购。

## 其他器件的采购决定

贵芯片只买装机数量：STM32、DRV8316R、BQ25798、TPS26630、INA228、LM74800 各 1 颗；TLV1704 是 2 颗装机，LMR33630 是 2 颗装机，CSD18540Q5B 是 3 颗装机，不是备件。没有把不同芯片写成免改电路/固件的“国产兼容替换”。这些芯片本次保留型号；140 元 MCU、80 元输入保护的原表价格仍有重新询价价值，但没有把未证实的低价算进节省额。

阻容改为少量调试包装，单个阻容位号尚未展开，表中不虚构“精确装机个数”。电阻原价仅 0.02 元/颗，当前主要节省来自购买量。LED 按 24 装机＋6 备料，轻触按键 7 装机＋3 备料；不省掉过压、过流、隔离和独立制动保护。

原 HSA2510RJ 只买 1 只作台架制动负载，不能把其铝壳体直接塞进旋钮；内置制动件要按实际回灌能量和温升另行定型，相关费用没有计入本次已填价合计。

## 接头、排线与屏幕

板间低电流信号改用 FH12-10S-0.5SH(55) ×4 装机、备 1；10P/0.5 mm/100 mm 同面 FFC ×2 装机、备 1。最终针序和接点朝向需按重排后的板图复核。普通 FFC 不承载电机或 LED 主功率。电源用 XT30U 公母共 3 对；UVW 焊接到焊盘并做应力释放，避免重复购买相线接插件。NTC 座、胶壳、压接端子以及热缩管均已纳入同一 sheet。[Hirose FH12](https://www.hirose.com/product/p/CL0586-0522-3-55)、[JST PH](https://www.jst-mfg.com/product/pdf/eng/ePH.pdf)

Waveshare 完整模组附带 SH1.0 12PIN 线，D02 单列说明但购买量为 0，费用包含在 D01。原 GH 1.25 mm 8P 接头不能直接插到显示 J1。保留完整屏幕＋ESP32 在固定托盘上，走线通过机内固定空心柱；不穿裸 AMOLED 的高速 FPC，不把厂配插头硬穿过小孔。[官方套装清单](https://www.waveshare.com/product/esp32-s3-touch-amoled-1.32.htm)

J1-11/12 是 UART TX/RX、1 是 GND，项目原来的 GP1 故障线和 USB 差分信号仍需保留。J1-3 标为 VCC3V3，不能接 5 V；供电方向、可用电流和反灌路径须完成原理图审查后确定。**没有把“4 根线”冻结成整机线束**，也没有证明原配线已通过最终柱孔装配和信号完整性测试。[官方原理图](https://files.waveshare.com/wiki/ESP32-S3-Touch-AMOLED-1.32/ESP32-S3-Touch-AMOLED-1.32-schematic.pdf)

## 隐藏屏幕结构

保留原厂编码器电机，改成偏置 GL30 → 短同步带 → 中空旋转轴。固定屏柱从中心穿过并固定到机内底座，旋转轴和外圈围绕固定柱转，因此屏幕不随电机旋转，外观没有外置屏幕桥架。电机、皮带与从动轴承座装在同一按压平台，按压时整体移动 0.35 mm；用独立直线导向约束倾斜。

[R3 隐藏核心 STEP](../output/models/GL30_R3_HIDDEN_CORE/GL30_R3_HIDDEN_CORE_ASSEMBLY.step) 与 [校核 JSON](../output/models/GL30_R3_HIDDEN_CORE/verification.json) 是结构布置研究。现阶段不包含全机电池/PCB/按键/紧固件布置和公差寿命验证，不能直接作为量产或开模文件。屏幕模组官方 STEP 存在无效拓扑，仅用于参考预览；主 STEP 不冒充已修复原厂模型。

本轮核心外包络为 104×100 mm，机壳前高 30、后高 62 mm，含旋钮最大高度约 79.49 mm。为把同步带藏到面板下，内部传动整体下降 4 mm，并增加机身高度，保留旋钮外露握持高度。36T/2GT 的 1:1 传动、42 mm 中心距对应名义带长 156 mm；皮带型号、张紧、回差和扭转刚度仍需样机确认，不据几何包络承诺直驱同等手感。

原编码器测量电机轴，皮带弹性产生的旋环角度偏差尚未实测。遮光裙圈仅遮住旋钮根部的内部零件，不承担屏幕支撑；名义径向间隙 0.4 mm，最大按压时轴向间隙 0.55 mm，均不是装配公差保证。

隐藏固定柱与同平台按压的剖面概念

A/B/C 板厚目标仍为 1.2 mm，C 板主环外径 66、内径 58 mm 暂定。A/B 因电机偏置及电感焊盘变化必须重排，**旧板框不可当成本轮制造尺寸**。电池按一个完整 3S 保护/均衡/NTC 包采购，60×32×21 mm 仅为待布局目标，不代表已通过整机空间验证。

## 文件验证

已完成：原表价格和数量逐行核算、61 个原电子器件条目覆盖、ID 去重、贵芯片零备件策略检查、已有量扣减/补价格实时重算、替代价不污染原价、公式错误扫描、导出后独立读取以及表格图片检查。[BOM 核算记录](../outputs/01a08963-e2d7-71e2-a353-8710a44dc948/bom-cost-down/bom-verification.json)、[XLSX 回读记录](../outputs/01a08963-e2d7-71e2-a353-8710a44dc948/bom-cost-down/xlsx-readback-verification.json)。

R3 导出含 35 个部件、42 个有效实体；生成器对 0/0.175/0.35 mm 按压位置进行 918 项固定实体检查，失败 0。主线程另从导出的 STEP 重复 363 项碰撞检查，并检查三臂连续全周旋转包络，结果通过。最大按压时最低运动件距 2 mm 底板上表面约 2.420 mm。C 板与 LED 使用 1.2 mm＋0.8 mm 的独立包络，没有以零厚度光圈代替板件。[独立 STEP 回读记录](../outputs/01a08963-e2d7-71e2-a353-8710a44dc948/bom-cost-down/r3-independent-readback.json)

本轮没有下单、打板、固件烧录、电机通电或实际器件替换测试。

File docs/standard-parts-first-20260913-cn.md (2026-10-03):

# GL30：标准件优先，保留现有塑料外壳

2026-09-13。依据本轮用户要求更新机械设计原则。最新机械库存按“只有电机和3D打印件”处理；已打印外壳继续使用。[简单购买/加工清单](mechanical-buy-make-simple-20260913-cn.md)仅覆盖机械试装，电子器件不在本轮盘点范围。

后续已按现货螺钉头部尺寸完成[局部适配](standard-fastener-fit-20260913-cn.md)。下方标准轮排布仍为设计基准，最新总装、弹片孔距和导轨螺孔以该适配包为准。

## 已确定的边界

1. 外壳、底盖、收腰握环、侧键/电源键位置和可见灯圈沿用当前实物对应的 R8 几何。内部调整优先适应这些接口，不为了带轮凸台改外观。
2. 采购顺序：**标准成品直接用 → 调整内部支架适应成品 → 标准成品少量车削/扩孔 → 最后才定制整件**。两只带轮取消“从毛坯定制齿形”的默认路线。
3. 保留 1:1 短同步带、双轴承、防倾导向和隐藏固定屏幕。标准化必须维持刚度、低摩擦和反向反馈；不得靠大张力或大轴承预紧掩盖松动。
4. 上一版“18种、24件加工件”是旧几何的分类，不再作为整套定制加工采购指令。合格打印件继续用于试装，不要求整套重打。

## 带轮选型的实际依据

[MISUMI 2GT 型 A/B 形目录，825–826页](https://www.misumi.com.cn/pdf/fa/2013/p825.pdf)中的 A 形 36 齿、6 mm 带宽轮：节径 22.92、齿顶径 22.41、法兰直径 27、齿槽工作宽度 7、总宽 10.3 mm。该页 36 齿 H/P 孔最大列到 10 mm；**它不是直接适配当前 12 mm 输出轴的成品**。B 形总长 18 mm，占用更大的轴向空间。这是目录尺寸依据，不代表当前本地店铺库存/价格已经确认。

[Phidgets 的 TRM4107 商品页](https://www.phidgets.com/?prodid=756)证明市场上有标称 36 齿、12 mm 孔的成品；但该页下载 PDF 的型号写 Z32、齿顶径 19.86，与页面的36齿矛盾。本次保留这项差异，不按该错误关联图冻结36齿尺寸，也不推荐照图直接下单。国内同规格供货仍须给出一致的尺寸图。

现 R8 电机带轮厚度 7.35 mm，电机前端至上方现有几何基准约 9.95 mm；10.3 mm 标准 A 形轮也不能在原位置凭空装入。核查顺序是电机座可下移多少、两轮工作面能否同步调整、输出侧与轴承盖/三臂架/固定屏幕的净空。只有这些内部调整不能成立，才削短成品凸台或修改端面；6 mm 带槽及挡边保持有效，避免改动齿形。

两轮均为36齿、节距2 mm、中心距42 mm时，闭口带节线长为 `2×42 + 36×2 = 156 mm`。若最终更换齿数或中心距，重新计算配套带长，不能沿用旧长度而硬拉紧。两只同齿数带轮一起换成40齿仍是1:1，但中心距42 mm时带长变成164 mm，且目录法兰变大；这不是当前优先方案。

## 已生成的标准轮内部排布候选

[内部装配图](../outputs/r9-standard-parts/standard_drive_candidate/01_标准带轮内部排布.png) · [与R8对照图](../outputs/r9-standard-parts/standard_drive_candidate/02_传动排布对照.png) · [完整候选STEP](../outputs/r9-standard-parts/standard_drive_candidate/GL30_STANDARD_DRIVE_LAYOUT_CANDIDATE.step) · [几何核查数据](../outputs/r9-standard-parts/standard_drive_candidate/verification.json)

候选的电机轮以 `GPA36GT2060-A-P10` 为尺寸基准，保留标准10 mm孔和成品固定螺钉方案；输出轮以同型标准轮扩至12 mm为可实施的备选路线。**优先寻找尺寸一致的12孔成品，找不到再扩孔；没有把目录里不存在的A36-H12写成可直接购买的型号。** 目录品牌是尺寸依据，不要求买该品牌的高价件；国产同型须有一致的尺寸图及配对齿形。两只轮都保留10.3 mm总宽、7 mm带槽和完整挡边，不削薄铆接挡边。

已经在候选模型中完成的内部调整：

- 电机向壳内移2.85 mm。新电机滑板的锁紧脚、张紧槽及其承压面留在原处，加宽连接耳；仅对内部按压底板做局部避让。没有下移整块旧支架后再挖底盖。
- 两只6901一起向壳内移3 mm，**13 mm轴承中心距保持不变**；轴承筒底部与导轨安装基准不动，中空轴仍保留12 mm配合段和8.8 mm通孔。
- 三臂架仅加长中央向下的连接段，握环端三孔、握环外形和高度不动。候选仍需核定中央夹持材料与长期蠕变，不能直接把PETG装配样当成已合格的长期传扭夹持件。
- 电机转接毂改为简单端面法兰+10 mm实心定位段，取消电机侧M14细牙和专用薄锁母。成品轮采用其固定螺钉压在定位段平面上；具体螺钉、工具路径、防松与反向微动还需按实物轮确认，STEP没有把它们画成已验证的真实螺纹。
- 更新两路电机线尾的空间预留，板端位置不动；固定屏管、屏幕托盘、灯圈、外壳和底盖原样沿用。

核查结果：176个命名对象的STEP已重新读取，几何有效；外壳/底盖/握环/灯圈/固定屏管/托盘的顶点、面面积与重心、体积、包围盒与原版相符。张紧位置`-0.5/0/+0.5 mm`与按压行程`0/0.175/0.35 mm`的9种组合，共4995次指定对象对比，没有新增正体积干涉。静态剩余交集为原有螺纹名义啮合及带齿包络重叠，均未增加。原R8 STEP的SHA256保持`98187acd4557650db18fc827d60f13b573a35eafc45ec5af02e06f6c57cda339`。

这些结果证明候选的**名义空间排布可保留外壳**，不证明公差、间隙余量、强度、真实螺钉锁紧和手感已通过。三臂架夹持链、最小壁厚/加工刀路、线束弯曲半径和实物带轮配合仍待确认；本轮不发新的整套打印任务，也不把候选STEP作为下单图。

## 原18种零件逐项处理

“目标”表示本轮设计安排；没有供应商尺寸及装配核对的条目不冒充已完成替换。

| 原编号 | 原名称/装配数量 | 本轮处理 | 为何保留或调整 |
|---|---|---|---|
| M09 | 电机侧同步带轮 ×1 | 候选已按标准A形P10铝轮排布 | 完整齿槽、挡边和10 mm孔保留；成品固定螺钉接口需供应商实物复核 |
| M10 | 旋钮侧同步带轮 ×1 | 标准12孔成品优先；候选以A形10孔轮扩孔排布 | 不把空心轴车薄到10 mm来迁就目录孔径，不自制同步齿 |
| 36 | 电机转接毂 ×1 | 候选已简化为端面法兰+10 mm实心定位段 | 电机前端为4-M3、PCD20，无外伸标准轴；保留这一个必要转接接口 |
| 37 | M14×0.75薄锁母 ×1 | 已从候选模型取消 | 改用成品轮原有固定螺钉接口；实际防松、夹紧与反向微动未验证 |
| 04 | 轴承筒 ×1 | 双6901保留；先核标准轴承座外廓，装不下再保留通孔车件 | 轴承同轴度与径向/轴向约束直接影响手感；不拆成两个可摇动的软座 |
| 20 | 中空输出轴 ×1 | 保留12 mm轴承配合段，简化台阶/锁紧结构 | 内孔须避让8 mm固定屏管；普通装饰管不能充当已合格轴承轴 |
| 05 | 外圈隔套 ×1 | 优先成品精密隔套；没有合适长度则简单车端面 | 与内圈定位链配合，不能任意堆普通冲压垫圈 |
| 33 | 内圈隔套 ×1 | 与05成组选择/定长 | 不是把内外两套都写7 mm就自动得到正确游隙 |
| 26 | 内圈上隔垫 ×1 | 优先精密调整垫片组合 | 标准环的内外径必须只接触相应圈，不擦防尘盖；1.3 mm可否组合取决于实物环尺寸 |
| 35 | M12×0.75薄锁母 ×1 | 优先标准锁紧件，但当前不直接删除 | 当前同时夹持内圈链、带轮及三臂架；必须先分清传扭与轴承定位功能 |
| 32 | 导轨背板 ×1 | 保留简单板料钻孔/切割，先用现有件 | 已是简单工艺，不值得为少一块板改变壳体或导轨安装基准 |
| 06 | 轴承薄压盖 ×1 | 简单薄板切割/钻两孔 | 带孔的外圈盖不是一只普通标准垫圈能直接替代；可以低成本工艺制作 |
| 24 | 板间隔管 ×4 | 标准隔离柱/定长管料优先 | 13.6 mm为现设计尺寸；内部板间距可适应成品长度，核对后再更改，避免复制无意义非标尺寸 |
| 09 | 固定屏柱 ×1 | 标准8×6直管定长 | 已有短料继续用；上端细牙及锁环随屏幕支座一起优化 |
| 25 | 按压止挡 ×3 | 目标改为标准平端调节螺钉或销+可靠调整片 | 保留独立硬止挡，避免把0.35 mm行程做成必须定长5.15 mm的一次性高成本配合 |
| 38 | 按压弹片 ×1 | 标准弹簧片料简单切孔，暂保留 | 形状简单；材料状态与真实开关触发力需要试装，不用刚性塑料代替回弹功能 |
| 34 | 屏柱薄锁环 ×2 | 与屏幕托盘夹持方式一并优化，暂缓加工 | 不能只删锁环留下会转动/滑落的托盘；也不在薄管上用尖头顶丝压坑 |
| 22 | 固定屏幕托盘 ×1套 | 优先塑料支座或薄板+成品隔柱 | 保持屏幕高度及3个原厂安装点，降低中心叠厚/三个凸台整体铣削的成本 |

标准螺钉、螺母、热熔嵌件、6901轴承、MGN7导轨/滑块、同步带及现有板柱继续按标准件处理。电机和已购FOC元器件不重复计购。上述表不承诺“只剩几件加工”，直到标准件型号与新连接方式验证结束。

## 塑料外壳与手感

现有 PETG 打印外壳继续用于装配。最终单套塑料切削件优先询价黑色 ABS，保持外形；[Protolabs ABS 加工资料](https://www.protolabs.com/services/cnc-machining/plastics/abs/)列明其可加工性及电子壳体用途。这是材料路线，未证明当前壳体所有内部倒扣都适合普通三轴加工；只有确认刀具无法到达的局部才提出必要调整，不先重画外观。承受轴承配合与夹紧力的金属轴系和转接件不因为外壳选塑料就全部改成塑料。

触摸面优先细哑光、倒钝现有边缘；配合面、螺钉座与灯圈净空不靠厚涂层补偿。不默认增加软胶层、改变握环直径/收腰、扩大壳体或移动按钮。

手感验收关注：

- 完整转一圈没有明显周期性紧点、擦壳、蹭带或轴向窜动。
- 小角度反转没有连接件空走；标准带本身的弹性与齿部迟滞仍需测量。
- 正压、偏压均顺畅，MGN7导向和回位弹簧承担各自功能，不让屏幕或电池承受按压力。
- 同一电机分别测装带前后起动阻力、扭矩—相对转角和反向迟滞；CAD无碰撞不代表这些指标已经合格。

[Gates 精密传动设计手册](https://www.gates.com/content/dam/documents-library/catalogs/light-power-and-precision-manual.pdf)将定位误差区分为带体伸长、齿隙与齿部变形。配对带和轮、适度张紧及刚性安装是设计依据；不能承诺成品同步传动天然零回差。

## 本轮证据状态

已核读R8源码、已有采购分类及供应商目录；标准轮内部候选的STEP、图和核查结果放在 `outputs/r9-standard-parts/standard_drive_candidate/`。外壳不做几何修改。旧R8加工分类和XLSX保留供对照，未假称已全部改成标准件；新的采购与制造决策按本文件的标准件优先顺序推进。

读回核对遇到OCC对两次独立载入的同一冻结外壳返回异常的重合布尔结果；没有以此结果判断外壳是否改变。最终采用源对象沿用记录、文件哈希、双向顶点位置和面面积/重心签名，加上体积与包围盒比较，记录在`readback.json`。碰撞检查针对指定对象和离散位置，不是整机全工况的制造验收。

DeepSeek V4 Pro 的独立意见已读完。接受其空心轴薄壁、卡簧不能替代传扭夹紧、预紧不能过大的提醒；没有接受“两只轮一起改40齿会破坏1:1”或“未做内部空间检查就否定标准轮”的结论。实物回差、强度、预紧、按压和长期塑料蠕变未验证。

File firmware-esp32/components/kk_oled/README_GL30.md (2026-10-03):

# GL30 KK_OLED RGB565 组件

本目录是 GL30 ESP32-S3 466×466 彩色 AMOLED 的 KK_OLED 图形核心副本。上游 KK_OLED 的图元、u8g2 字体解析、UTF-8 文字、XBM 读取和旋转采样算法保留在本组件中；上游运行时原本是 1-bit 页式单色 OLED，本副本已将显存核心改为原生 RGB565 全帧布局，因此不宣称上游库原生支持彩色屏。

## 帧布局和提交

- 物理尺寸固定为 `466×466`，像素按行主序连续存放。
- 每个像素为 `uint16_t` RGB565；每份帧缓冲区为 `466×466×2 = 434312` 字节。
- 运行时只保留两份静态帧缓冲区。定义 `ESP_PLATFORM` 时，帧缓冲区带 `EXT_RAM_BSS_ATTR`，由 ESP-IDF 的外部 BSS/PSRAM 配置承载；主机编译使用普通静态存储。
- 更新前按整帧比较新旧缓冲区。没有差异时不调用 driver；阻塞提交成功后交换缓冲区，失败则保持待提交帧并强制下一次全帧发送。
- 异步更新会在调用 BSP driver 前设置核心 Busy 状态并交换绘制索引，传输指针在整个异步过程保持冻结。driver 必须在真实完成或错误时调用 `OLED_InternalTransferFinished` 一次；未接入真实 IT/DMA 时，`OLED_DriverWriteIT` 和 `OLED_DriverWriteDMA` 应返回 `OLED_UNSUPPORTED`，不能用阻塞发送伪装异步。

平台 driver 不在本组件内。BSP driver 通过 `OLED_InternalGetTransferBuffer()` 取得 `const uint16_t *` 的完整 466×466 帧，并实现 `OLED_DriverInit`、`OLED_DriverWriteBlocking`、`OLED_DriverWriteIT`、`OLED_DriverWriteDMA`、`OLED_DriverIsBusy`、对比度/省电控制及异步事件转发。

## 颜色接口

```c
void OLED_SetColor(uint16_t foreground, uint16_t background);
void OLED_BlitRGB565(int16_t x, int16_t y, uint16_t width, uint16_t height,
                     const uint16_t *pixels);
void OLED_BlendPixelRGB565(int16_t x, int16_t y, uint16_t color,
                           uint8_t alpha);
```

`OLED_Clear()` 使用当前背景色，`OLED_Fill()` 使用当前前景色。普通图元的 `OLED_DRAW_SET` 写前景色，`OLED_DRAW_CLEAR` 写背景色，`OLED_DRAW_XOR` 对当前 RGB565 像素逐位取反。`OLED_BG_SOLID` 延续上游文字/XBM 的背景反操作语义；`OLED_BG_TRANSPARENT` 保留透明背景。RGB565 位图源是行主序 `uint16_t` 数组，按主机字节序读取。位图和像素混合都会经过当前裁剪窗口及画布旋转映射。

组件不内置或改写上层视觉资源；上层可用 `OLED_BlitRGB565` 继续呈现日照金山照片和彩色圈。

## 许可和范围

图形源和许可证保留上游 MIT 条款，详见同目录 `LICENSE.txt`。本组件只包含图形核心，不包含板级显示控制器初始化、总线传输、PSRAM 启用配置或 KK_UI 业务界面；这些由 `firmware-esp32/bsp` 和上层 UI 集成负责。

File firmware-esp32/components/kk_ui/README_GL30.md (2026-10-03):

# KK_UI in GL30

Upstream: https://gitee.com/keysking/kk_ui
Commit: 582c3442ecbc539c1c82a342676b5b2eda69eee0 (MIT, license included).

The two private screen constants are changed from 128x64 to 466x466.
The project config selects asynchronous DMA refresh at 28 ms and disables the unused
128x64 templates and overlays. All GL30 pages are implemented in the upstream
custom-page callbacks. Input dispatch, frame scheduling, display ownership,
error propagation and refresh state remain KK_UI's responsibility.

Do not compile the runtime inside `.agents/skills`; those are upstream skill
assets. Project runtime sources live here.

Known model changes/animations explicitly mark the rendered draw buffer to skip
its optional full-frame comparison. Generic invalidation/default OLED updates
still deduplicate. Busy and error recovery contracts remain in KK_OLED; fatal
BSP DMA faults quarantine memory until reset. See the current display audit in
`docs/esp32-dirty-audit-20260915-cn.md` at the repository root.

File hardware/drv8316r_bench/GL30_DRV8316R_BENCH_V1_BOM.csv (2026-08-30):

Item | Category | Designators | QtyPerBoard | SuggestedBuyQty | ValueFunction | Manufacturer | MPN | LCSC | Package | KeySpec | Mount | StockSnapshot | UnitCNY | LineCNY | ImportDefault | Validation | Notes | ProductURL
1 | 驱动器 | U1 | 1 | 2 | 三相集成 FET 电机驱动器 | Texas Instruments | DRV8316RRGFR | C5218861 | VQFN-40 5x7 mm, EP | 40 V max；SPI；集成 CSA | SMT/热焊盘 | 337 | 27.95 | 27.95 | YES | 精确 C 号；TI RGF-40 | 中心 41 脚为 AGND/热焊盘；逐项核引脚与钢网窗。 | https://www.lcsc.com/product-detail/C5218861.html
2 | 比较器 | U2,U3 | 2 | 3 | 四路高压开漏比较器 | Texas Instruments | TLV1704AIPWR | C181596 | TSSOP-14 (PW) | 2.2–36 V；560 ns typ | SMT | 187 | 14.15 | 28.3 | YES | 精确 C 号；TI PW-14 | PWR 仅为卷带后缀；与图纸 TLV1704AIPW 电气和封装一致。 | https://www.lcsc.com/product-detail/C181596.html
3 | 保护 | F1 | 1 | 3 | 3 A 延时保险丝 | Littelfuse | 0454003.MR | C142863 | 2410 / 6125 | Slo-Blo；125 V；I²t=20.16 A²s | SMT | 337 | 2.7964 | 2.7964 | YES | 官方 452/454 曲线已核 | 替代已排除的快断 0453003.MR；首次上电仍需限流缓升。 | https://www.lcsc.com/product-detail/C142863.html
4 | 保护 | D1 | 1 | 3 | 串联肖特基二极管 | MDD | SS56B | C14651 | SMB / DO-214AA | 60 V；5 A；Vf≤0.7 V@5 A | SMT/散热铜 | 12373 | 0.5214 | 0.5214 | YES | 精确 C 号；规格匹配 | 正向朝 VM；2 A 时必须实测温升与压降。 | https://www.lcsc.com/product-detail/C14651.html
5 | 保护 | D2 | 1 | 3 | 单向 TVS | Littelfuse | SMBJ18A | C151256 | SMB / DO-214AA | 18 V standoff；单向 | SMT | 1282 | 0.8972 | 0.8972 | YES | 精确 C 号；规格匹配 | 阴极接 VM、阳极接 GND；不承担持续再生制动。 | https://www.lcsc.com/product-detail/C151256.html
6 | 连接器 | J1 (J_PWR) | 1 | 2 | 2Pin 电源螺钉端子 | KEFA | KF128-5.08-2P-AA | C474952 | THT, P=5.08 mm | 24 A；250 V；AWG12–22 | THT | 7589 | 1.1771 | 1.1771 | YES | 精确 5.08 mm | 板边放置；正反面标 VM_RAW+/GND。 | https://www.lcsc.com/product-detail/C474952.html
7 | 连接器 | J2 (J_MOTOR) | 1 | 2 | 3Pin 电机螺钉端子 | KEFA | KF128-5.08-3P-AA | C474953 | THT, P=5.08 mm | 24 A；250 V；AWG12–22 | THT | 2997 | 1.8769 | 1.8769 | YES | 精确 5.08 mm | 板边放置；标 A/B/C。 | https://www.lcsc.com/product-detail/C474953.html
8 | 连接器 | J3 (J_CTRL) | 1 | 2 | 2×10 简牛座/控制头 | LAILAN | LAIL-SI-2.54-2X10P-ZC | C55118382 | THT, 2×10, P=2.54 mm | 3 A；直插；带防呆框 | THT | 113 | 1.3836 | 1.3836 | YES | 规格与 20Pin 定义匹配 | 引脚必须与 CONTROL_HEADER_PINOUT.csv 一一核对；下单前再看 1 脚方向。 | https://www.lcsc.com/product-detail/C55118382.html
9 | 电容 | C1 | 1 | 2 | 470 µF / 50 V 电解 | Panasonic | EEUFR1H471 | C178708 | Radial D12.5×L20 mm, P=5.0 mm | 22 mΩ；2.26 A@100 kHz | THT/人工封装 | 6460 | 4.96 | 4.96 | NO | 采购 C 号已核；源 CAD 畸形 | 不进默认导入 CSV；按 Panasonic 官方 D12.5/P5.0/引线Ø0.6 mm 手建封装。 | https://www.lcsc.com/product-detail/C178708.html
10 | 电容 | C2 | 1 | 3 | 10 µF / 50 V X7R | Murata | GRM32ER71H106KA12L | C77102 | 1210 | ±10%；50 V；X7R | SMT | 13879 | 2.0158 | 2.0158 | YES | 精确 C 号；规格匹配 | VM 陶瓷 bulk；注意直流偏压降容。 | https://www.lcsc.com/product-detail/C77102.html
11 | 电容 | C3,C23 | 2 | 5 | 1 µF / 50 V X7R | Samsung | CL21B105KBFNNNE | C28323 | 0805 | ±10%；50 V；X7R | SMT | 100399 | 0.2699 | 0.5398 | YES | 精确 C 号；规格匹配 | C3=VM 去耦；C23=U2/U3 共享供电去耦。 | https://www.lcsc.com/product-detail/C28323.html
12 | 电容 | C4,C5,C6,C10,C12,C21,C22 | 7 | 20 | 100 nF / 50 V X7R | Samsung | CL10B104KB8NNNC | C1591 | 0603 | ±10%；50 V；X7R | SMT | 20564 | 0.0717 | 0.5019 | YES | 精确 C 号；规格匹配 | 3×VM、VREF、nSLEEP、2×比较器局部去耦。 | https://www.lcsc.com/product-detail/C1591.html
13 | 电容 | C7 | 1 | 10 | 47 nF / 50 V X7R | Samsung | CL10B473KB8NNNC | C1622 | 0603 | ±10%；50 V；X7R | SMT | 6168 | 0.0625 | 0.0625 | YES | 精确 C 号；规格匹配 | CPH–CPL 飞跨电容，紧贴 U1。 | https://www.lcsc.com/product-detail/C1622.html
14 | 电容 | C8,C9 | 2 | 10 | 1 µF / 25 V X5R | Samsung | CL10A105KA8NNNC | C5673 | 0603 | ±10%；25 V；X5R | SMT | 91531 | 0.1714 | 0.3428 | YES | 精确 C 号；规格匹配 | C8=CP–VM；C9=AVDD–AGND。 | https://www.lcsc.com/product-detail/C5673.html
15 | 电容 | C11 | 1 | 5 | 22 µF / 25 V X5R | Samsung | CL21A226MAQNNNE | C45783 | 0805 | ±20%；25 V；X5R | SMT | 80968 | 1.684 | 1.684 | YES | 精确 C 号；规格匹配 | Buck Resistor Mode 必装；FB_BK–GND_BK，紧贴 U1。 | https://www.lcsc.com/product-detail/C45783.html
16 | 电容 | C13,C14,C15 | 3 | 10 | 33 pF / 50 V C0G | Yageo | CC0603JRNPO9BN330 | C107047 | 0603 | ±5%；C0G/NP0 | SMT | 20739 | 0.0484 | 0.1452 | YES | 精确 C 号；规格匹配 | SOA/B/C ADC 支路，各自独立。 | https://www.lcsc.com/product-detail/C107047.html
17 | 电容 | C16,C17,C18 | 3 | 10 | 100 pF / 50 V C0G | Yageo | CC0603JRNPO9BN101 | C14665 | 0603 | ±5%；C0G/NP0 | SMT | 21326 | 0.0558 | 0.1674 | YES | 精确 C 号；规格匹配 | SOA/B/C 比较器支路，各自独立。 | https://www.lcsc.com/product-detail/C14665.html
18 | 电容 | C19,C20,C26 | 3 | 10 | 10 nF / 50 V X7R | Yageo | CC0603KRX7R9BB103 | C100042 | 0603 | ±10%；50 V；X7R | SMT | 68999 | 0.0661 | 0.1983 | YES | 隔离库生成通过 | V_LOW、V_HIGH、VBUS_TRIP 滤波；替换源 CAD 403 的 C1589。 | https://www.lcsc.com/product-detail/C100042.html
19 | 电容 | C24,C25 | 2 | 10 | 1 nF / 50 V X7R | Samsung | CL10B102KB8NNNC | C1588 | 0603 | ±10%；50 V；X7R | SMT | 121606 | 0.0558 | 0.1116 | YES | 隔离库生成通过 | VBUS_DIV_RAW 与 VBUS_SENSE 各一只；替换源 CAD 403 的 C100040。 | https://www.lcsc.com/product-detail/C1588.html
20 | 电阻 | R1,R14,R15 | 3 | 20 | 22 Ω / 1% | UNI-ROYAL | 0603WAF220JT5E | C23345 | 0603 | 0.1 W；±1% | SMT | 59839 | 0.0111 | 0.0333 | YES | 精确 C 号；规格匹配 | R1=Buck；R14/R15=SPI SCK/MOSI 串联。 | https://www.lcsc.com/product-detail/C23345.html
21 | 电阻 | R2-R7 | 6 | 20 | 47 Ω / 1% | UNI-ROYAL | 0603WAF470JT5E | C23182 | 0603 | 0.1 W；±1% | SMT | 10715 | 0.0262 | 0.1572 | YES | 精确 C 号；规格匹配 | 六路 PWM 串联阻尼。 | https://www.lcsc.com/product-detail/C23182.html
22 | 电阻 | R8-R13,R19 | 7 | 20 | 100 kΩ / 1% | UNI-ROYAL | 0603WAF1003T5E | C25803 | 0603 | 0.1 W；±1% | SMT | 155694 | 0.0251 | 0.1757 | YES | 精确 C 号；规格匹配 | 6×PWM 下拉；1×nSLEEP 下拉。 | https://www.lcsc.com/product-detail/C25803.html
23 | 电阻 | R16,R17,R18 | 3 | 20 | 10 kΩ / 1% | UNI-ROYAL | 0603WAF1002T5E | C25804 | 0603 | 0.1 W；±1% | SMT | 17027 | 0.015 | 0.045 | YES | 精确 C 号；规格匹配 | CS_N、DRVOFF、nSLEEP 上拉。 | https://www.lcsc.com/product-detail/C25804.html
24 | 电阻 | R20-R22,R39 | 4 | 20 | 0 Ω 跳线 | UNI-ROYAL | 0603WAF0000T5E | C21189 | 0603 | 0 Ω；0.1 W | SMT | 140970 | 0.0158 | 0.0632 | YES | 精确 C 号；规格匹配 | 3×SO 隔离；1×AVDD→VREF/ILIM。 | https://www.lcsc.com/product-detail/C21189.html
25 | 电阻 | R23-R28,R36 | 7 | 20 | 1 kΩ / 1% | UNI-ROYAL | 0603WAF1001T5E | C21190 | 0603 | 0.1 W；±1% | SMT | 95467 | 0.0199 | 0.1393 | YES | 精确 C 号；规格匹配 | 6×SO ADC/CMP 独立支路；1×VBUS_SENSE 串联。 | https://www.lcsc.com/product-detail/C21190.html
26 | 精密电阻 | R29,R32,R34,R38 | 4 | 10 | 100 kΩ / 0.1% | Yageo | RT0603BRD07100KL | C122538 | 0603 | ±0.1%；25 ppm/°C | SMT | 44741 | 0.2068 | 0.8272 | YES | 精确 C 号；规格匹配 | V_LOW/V_HIGH/VBUS_DIV/VBUS_TRIP 精密分压。 | https://www.lcsc.com/product-detail/C122538.html
27 | 精密电阻 | R30,R31 | 2 | 5 | 21.0 kΩ / 0.1% | RESI | PTFR0603B21K0N9 | C2692847 | 0603 | ±0.1%；10 ppm/°C | SMT | 805 | 0.8711 | 1.7422 | YES | 精确阻值；高库存候选 | V_LOW/V_HIGH 对称窗口；首板按实测电流增益再调值。 | https://www.lcsc.com/product-detail/C2692847.html
28 | 电阻 | R33 | 1 | 10 | 2.2 kΩ / 1% | Yageo | RC0603FR-072K2L | C114662 | 0603 | 0.1 W；±1% | SMT | 3513 | 0.026 | 0.026 | YES | 隔离库生成通过 | HARD_FAULT_N 唯一上拉；替换源 CAD 403 的 C4190。 | https://www.lcsc.com/product-detail/C114662.html
29 | 精密电阻 | R35 | 1 | 5 | 20.0 kΩ / 0.1% | Vishay | TNPW060320K0BEEA | C844676 | 0603 | ±0.1%；25 ppm/°C；0.125 W | SMT | 1905 | 0.4834 | 0.4834 | YES | 隔离库生成通过 | VBUS_DIV_RAW 下臂；替换源 CAD 403 的 C723637。 | https://www.lcsc.com/product-detail/C844676.html
30 | 精密电阻 | R37 | 1 | 3 | 23.7 kΩ / 0.1% | Yageo | AT0603BRD0723K7L | C855730 | 0603 | ±0.1%；25 ppm/°C | SMT | 93 | 0.5254 | 0.5254 | YES | 精确阻值；库存偏低 | VBUS_TRIP 上臂；采购前复查库存，备选 C3919228。 | https://www.lcsc.com/product-detail/C855730.html
31 | 人工封装 | SJ1 (SJ_WAKE) | 1 | 0 | 默认闭合焊桥 | 自建 | SJ_2PAD_NC |  | 自建 SMD 焊桥 | 默认闭合；可割断 | PCB FEATURE |  | 0 | 0 | NO | 无 C 号；按手工页建 | 不进入 PartsBridge；位于 3V3_CTRL→10 kΩ→nSLEEP 前。
32 | 人工封装 | TP1-TP40 | 40 | 0 | 可夹持镀锡线环测试点 | 自制 | TP_LOOP_PTH_2P_P2.54 |  | 2×PTH, P=2.54 mm | 孔 1.0 mm；焊盘 2.0 mm；0.8 mm 线 | 手焊线环 |  | 0 | 0 | NO | 无 C 号；网名表已列 | 默认不买 40 个商业测试柱；可选 Keystone 5015/C2906768 会增加约 ¥68。
33 | 机械 | H1-H4 | 4 | 0 | M3 安装孔 | PCB | M3_NPTH_3.2 |  | NPTH Ø3.2 mm | 铜/器件禁布 Ø6.5 mm | PCB FEATURE |  | 0 | 0 | NO | 无 C 号；机械孔 | 是否加螺钉/隔离柱待机架尺寸确认。

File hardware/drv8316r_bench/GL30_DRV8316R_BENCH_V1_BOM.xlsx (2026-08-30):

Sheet: BOM_Full
GL30 DRV8316R 验证子板 V1 — 完整 BOM / PartsBridge AD 选料表
工程：GL30_DRV8316R_BENCH_V1 ｜ PartsBridge：0.3.7 ｜ 价格/库存快照：2026-08-30 ｜ 币种：CNY
总位号数(含TP/孔) | 119 | 导入唯一C号 | 29 | 1板物料估算 | ¥79.85 | 导入文件 | *_PartsBridge_Import.csv |  | 4层 / 1.6 mm |  | 70 × 55 mm |  | 本板不包含 |  | C号/规格/CSV/临时库
注意：PartsBridge 只负责把确认后的 C 号追加到 Altium 原生库；U1/U2/U3、保险丝、极性器件和连接器仍必须按厂家数据手册在 AD 中做最终引脚/封装/方向复核。
Item | 类别 | 位号 | Qty/板 | 建议采购数 | Value/功能 | 制造商 | MPN | LCSC | 封装 | 关键规格 | 装配 | 库存快照 | 单价 CNY | Line CNY | 导入 | 校验状态 | 备注 | 商品链接
1 | 驱动器 | U1 | 1 | 2 | 三相集成 FET 电机驱动器 | Texas Instruments | DRV8316RRGFR | C5218861 | VQFN-40 5x7 mm, EP | 40 V max；SPI；集成 CSA | SMT/热焊盘 | 337 | ¥27.9500 | ¥27.9500 | YES | 精确 C 号；TI RGF-40 | 中心 41 脚为 AGND/热焊盘；逐项核引脚与钢网窗。 | https://www.lcsc.com/product-detail/C5218861.html
2 | 比较器 | U2,U3 | 2 | 3 | 四路高压开漏比较器 | Texas Instruments | TLV1704AIPWR | C181596 | TSSOP-14 (PW) | 2.2–36 V；560 ns typ | SMT | 187 | ¥14.1500 | ¥28.3000 | YES | 精确 C 号；TI PW-14 | PWR 仅为卷带后缀；与图纸 TLV1704AIPW 电气和封装一致。 | https://www.lcsc.com/product-detail/C181596.html
3 | 保护 | F1 | 1 | 3 | 3 A 延时保险丝 | Littelfuse | 0454003.MR | C142863 | 2410 / 6125 | Slo-Blo；125 V；I²t=20.16 A²s | SMT | 337 | ¥2.7964 | ¥2.7964 | YES | 官方 452/454 曲线已核 | 替代已排除的快断 0453003.MR；首次上电仍需限流缓升。 | https://www.lcsc.com/product-detail/C142863.html
4 | 保护 | D1 | 1 | 3 | 串联肖特基二极管 | MDD | SS56B | C14651 | SMB / DO-214AA | 60 V；5 A；Vf≤0.7 V@5 A | SMT/散热铜 | 12373 | ¥0.5214 | ¥0.5214 | YES | 精确 C 号；规格匹配 | 正向朝 VM；2 A 时必须实测温升与压降。 | https://www.lcsc.com/product-detail/C14651.html
5 | 保护 | D2 | 1 | 3 | 单向 TVS | Littelfuse | SMBJ18A | C151256 | SMB / DO-214AA | 18 V standoff；单向 | SMT | 1282 | ¥0.8972 | ¥0.8972 | YES | 精确 C 号；规格匹配 | 阴极接 VM、阳极接 GND；不承担持续再生制动。 | https://www.lcsc.com/product-detail/C151256.html
6 | 连接器 | J1 (J_PWR) | 1 | 2 | 2Pin 电源螺钉端子 | KEFA | KF128-5.08-2P-AA | C474952 | THT, P=5.08 mm | 24 A；250 V；AWG12–22 | THT | 7589 | ¥1.1771 | ¥1.1771 | YES | 精确 5.08 mm | 板边放置；正反面标 VM_RAW+/GND。 | https://www.lcsc.com/product-detail/C474952.html
7 | 连接器 | J2 (J_MOTOR) | 1 | 2 | 3Pin 电机螺钉端子 | KEFA | KF128-5.08-3P-AA | C474953 | THT, P=5.08 mm | 24 A；250 V；AWG12–22 | THT | 2997 | ¥1.8769 | ¥1.8769 | YES | 精确 5.08 mm | 板边放置；标 A/B/C。 | https://www.lcsc.com/product-detail/C474953.html
8 | 连接器 | J3 (J_CTRL) | 1 | 2 | 2×10 简牛座/控制头 | LAILAN | LAIL-SI-2.54-2X10P-ZC | C55118382 | THT, 2×10, P=2.54 mm | 3 A；直插；带防呆框 | THT | 113 | ¥1.3836 | ¥1.3836 | YES | 规格与 20Pin 定义匹配 | 引脚必须与 CONTROL_HEADER_PINOUT.csv 一一核对；下单前再看 1 脚方向。 | https://www.lcsc.com/product-detail/C55118382.html
9 | 电容 | C1 | 1 | 2 | 470 µF / 50 V 电解 | Panasonic | EEUFR1H471 | C178708 | Radial D12.5×L20 mm, P=5.0 mm | 22 mΩ；2.26 A@100 kHz | THT/人工封装 | 6460 | ¥4.9600 | ¥4.9600 | NO | 采购 C 号已核；源 CAD 畸形 | 不进默认导入 CSV；按 Panasonic 官方 D12.5/P5.0/引线Ø0.6 mm 手建封装。 | https://www.lcsc.com/product-detail/C178708.html
10 | 电容 | C2 | 1 | 3 | 10 µF / 50 V X7R | Murata | GRM32ER71H106KA12L | C77102 | 1210 | ±10%；50 V；X7R | SMT | 13879 | ¥2.0158 | ¥2.0158 | YES | 精确 C 号；规格匹配 | VM 陶瓷 bulk；注意直流偏压降容。 | https://www.lcsc.com/product-detail/C77102.html
11 | 电容 | C3,C23 | 2 | 5 | 1 µF / 50 V X7R | Samsung | CL21B105KBFNNNE | C28323 | 0805 | ±10%；50 V；X7R | SMT | 100399 | ¥0.2699 | ¥0.5398 | YES | 精确 C 号；规格匹配 | C3=VM 去耦；C23=U2/U3 共享供电去耦。 | https://www.lcsc.com/product-detail/C28323.html
12 | 电容 | C4,C5,C6,C10,C12,C21,C22 | 7 | 20 | 100 nF / 50 V X7R | Samsung | CL10B104KB8NNNC | C1591 | 0603 | ±10%；50 V；X7R | SMT | 20564 | ¥0.0717 | ¥0.5019 | YES | 精确 C 号；规格匹配 | 3×VM、VREF、nSLEEP、2×比较器局部去耦。 | https://www.lcsc.com/product-detail/C1591.html
13 | 电容 | C7 | 1 | 10 | 47 nF / 50 V X7R | Samsung | CL10B473KB8NNNC | C1622 | 0603 | ±10%；50 V；X7R | SMT | 6168 | ¥0.0625 | ¥0.0625 | YES | 精确 C 号；规格匹配 | CPH–CPL 飞跨电容，紧贴 U1。 | https://www.lcsc.com/product-detail/C1622.html
14 | 电容 | C8,C9 | 2 | 10 | 1 µF / 25 V X5R | Samsung | CL10A105KA8NNNC | C5673 | 0603 | ±10%；25 V；X5R | SMT | 91531 | ¥0.1714 | ¥0.3428 | YES | 精确 C 号；规格匹配 | C8=CP–VM；C9=AVDD–AGND。 | https://www.lcsc.com/product-detail/C5673.html
15 | 电容 | C11 | 1 | 5 | 22 µF / 25 V X5R | Samsung | CL21A226MAQNNNE | C45783 | 0805 | ±20%；25 V；X5R | SMT | 80968 | ¥1.6840 | ¥1.6840 | YES | 精确 C 号；规格匹配 | Buck Resistor Mode 必装；FB_BK–GND_BK，紧贴 U1。 | https://www.lcsc.com/product-detail/C45783.html
16 | 电容 | C13,C14,C15 | 3 | 10 | 33 pF / 50 V C0G | Yageo | CC0603JRNPO9BN330 | C107047 | 0603 | ±5%；C0G/NP0 | SMT | 20739 | ¥0.0484 | ¥0.1452 | YES | 精确 C 号；规格匹配 | SOA/B/C ADC 支路，各自独立。 | https://www.lcsc.com/product-detail/C107047.html
17 | 电容 | C16,C17,C18 | 3 | 10 | 100 pF / 50 V C0G | Yageo | CC0603JRNPO9BN101 | C14665 | 0603 | ±5%；C0G/NP0 | SMT | 21326 | ¥0.0558 | ¥0.1674 | YES | 精确 C 号；规格匹配 | SOA/B/C 比较器支路，各自独立。 | https://www.lcsc.com/product-detail/C14665.html
18 | 电容 | C19,C20,C26 | 3 | 10 | 10 nF / 50 V X7R | Yageo | CC0603KRX7R9BB103 | C100042 | 0603 | ±10%；50 V；X7R | SMT | 68999 | ¥0.0661 | ¥0.1983 | YES | 隔离库生成通过 | V_LOW、V_HIGH、VBUS_TRIP 滤波；替换源 CAD 403 的 C1589。 | https://www.lcsc.com/product-detail/C100042.html
19 | 电容 | C24,C25 | 2 | 10 | 1 nF / 50 V X7R | Samsung | CL10B102KB8NNNC | C1588 | 0603 | ±10%；50 V；X7R | SMT | 121606 | ¥0.0558 | ¥0.1116 | YES | 隔离库生成通过 | VBUS_DIV_RAW 与 VBUS_SENSE 各一只；替换源 CAD 403 的 C100040。 | https://www.lcsc.com/product-detail/C1588.html
20 | 电阻 | R1,R14,R15 | 3 | 20 | 22 Ω / 1% | UNI-ROYAL | 0603WAF220JT5E | C23345 | 0603 | 0.1 W；±1% | SMT | 59839 | ¥0.0111 | ¥0.0333 | YES | 精确 C 号；规格匹配 | R1=Buck；R14/R15=SPI SCK/MOSI 串联。 | https://www.lcsc.com/product-detail/C23345.html
21 | 电阻 | R2-R7 | 6 | 20 | 47 Ω / 1% | UNI-ROYAL | 0603WAF470JT5E | C23182 | 0603 | 0.1 W；±1% | SMT | 10715 | ¥0.0262 | ¥0.1572 | YES | 精确 C 号；规格匹配 | 六路 PWM 串联阻尼。 | https://www.lcsc.com/product-detail/C23182.html
22 | 电阻 | R8-R13,R19 | 7 | 20 | 100 kΩ / 1% | UNI-ROYAL | 0603WAF1003T5E | C25803 | 0603 | 0.1 W；±1% | SMT | 155694 | ¥0.0251 | ¥0.1757 | YES | 精确 C 号；规格匹配 | 6×PWM 下拉；1×nSLEEP 下拉。 | https://www.lcsc.com/product-detail/C25803.html
23 | 电阻 | R16,R17,R18 | 3 | 20 | 10 kΩ / 1% | UNI-ROYAL | 0603WAF1002T5E | C25804 | 0603 | 0.1 W；±1% | SMT | 17027 | ¥0.0150 | ¥0.0450 | YES | 精确 C 号；规格匹配 | CS_N、DRVOFF、nSLEEP 上拉。 | https://www.lcsc.com/product-detail/C25804.html
24 | 电阻 | R20-R22,R39 | 4 | 20 | 0 Ω 跳线 | UNI-ROYAL | 0603WAF0000T5E | C21189 | 0603 | 0 Ω；0.1 W | SMT | 140970 | ¥0.0158 | ¥0.0632 | YES | 精确 C 号；规格匹配 | 3×SO 隔离；1×AVDD→VREF/ILIM。 | https://www.lcsc.com/product-detail/C21189.html
25 | 电阻 | R23-R28,R36 | 7 | 20 | 1 kΩ / 1% | UNI-ROYAL | 0603WAF1001T5E | C21190 | 0603 | 0.1 W；±1% | SMT | 95467 | ¥0.0199 | ¥0.1393 | YES | 精确 C 号；规格匹配 | 6×SO ADC/CMP 独立支路；1×VBUS_SENSE 串联。 | https://www.lcsc.com/product-detail/C21190.html
26 | 精密电阻 | R29,R32,R34,R38 | 4 | 10 | 100 kΩ / 0.1% | Yageo | RT0603BRD07100KL | C122538 | 0603 | ±0.1%；25 ppm/°C | SMT | 44741 | ¥0.2068 | ¥0.8272 | YES | 精确 C 号；规格匹配 | V_LOW/V_HIGH/VBUS_DIV/VBUS_TRIP 精密分压。 | https://www.lcsc.com/product-detail/C122538.html
27 | 精密电阻 | R30,R31 | 2 | 5 | 21.0 kΩ / 0.1% | RESI | PTFR0603B21K0N9 | C2692847 | 0603 | ±0.1%；10 ppm/°C | SMT | 805 | ¥0.8711 | ¥1.7422 | YES | 精确阻值；高库存候选 | V_LOW/V_HIGH 对称窗口；首板按实测电流增益再调值。 | https://www.lcsc.com/product-detail/C2692847.html
28 | 电阻 | R33 | 1 | 10 | 2.2 kΩ / 1% | Yageo | RC0603FR-072K2L | C114662 | 0603 | 0.1 W；±1% | SMT | 3513 | ¥0.0260 | ¥0.0260 | YES | 隔离库生成通过 | HARD_FAULT_N 唯一上拉；替换源 CAD 403 的 C4190。 | https://www.lcsc.com/product-detail/C114662.html
29 | 精密电阻 | R35 | 1 | 5 | 20.0 kΩ / 0.1% | Vishay | TNPW060320K0BEEA | C844676 | 0603 | ±0.1%；25 ppm/°C；0.125 W | SMT | 1905 | ¥0.4834 | ¥0.4834 | YES | 隔离库生成通过 | VBUS_DIV_RAW 下臂；替换源 CAD 403 的 C723637。 | https://www.lcsc.com/product-detail/C844676.html
30 | 精密电阻 | R37 | 1 | 3 | 23.7 kΩ / 0.1% | Yageo | AT0603BRD0723K7L | C855730 | 0603 | ±0.1%；25 ppm/°C | SMT | 93 | ¥0.5254 | ¥0.5254 | YES | 精确阻值；库存偏低 | VBUS_TRIP 上臂；采购前复查库存，备选 C3919228。 | https://www.lcsc.com/product-detail/C855730.html
31 | 人工封装 | SJ1 (SJ_WAKE) | 1 | 0 | 默认闭合焊桥 | 自建 | SJ_2PAD_NC |  | 自建 SMD 焊桥 | 默认闭合；可割断 | PCB FEATURE |  | ¥0.0000 | ¥0.0000 | NO | 无 C 号；按手工页建 | 不进入 PartsBridge；位于 3V3_CTRL→10 kΩ→nSLEEP 前。
32 | 人工封装 | TP1-TP40 | 40 | 0 | 可夹持镀锡线环测试点 | 自制 | TP_LOOP_PTH_2P_P2.54 |  | 2×PTH, P=2.54 mm | 孔 1.0 mm；焊盘 2.0 mm；0.8 mm 线 | 手焊线环 |  | ¥0.0000 | ¥0.0000 | NO | 无 C 号；网名表已列 | 默认不买 40 个商业测试柱；可选 Keystone 5015/C2906768 会增加约 ¥68。
33 | 机械 | H1-H4 | 4 | 0 | M3 安装孔 | PCB | M3_NPTH_3.2 |  | NPTH Ø3.2 mm | 铜/器件禁布 Ø6.5 mm | PCB FEATURE |  | ¥0.0000 | ¥0.0000 | NO | 无 C 号；机械孔 | 是否加螺钉/隔离柱待机架尺寸确认。

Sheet: PartsBridge_Import
PartsBridge AD 0.3.7 — 已确认 C 编号导入清单
真正导入时请选择同目录 GL30_DRV8316R_BENCH_V1_PartsBridge_Import.csv；该 CSV 只有第一列 lcsc，共 29 个唯一 C 号。C1 因源 CAD 畸形改为人工封装。
lcsc | MPN | 制造商 | 封装 | 使用位号 | 说明
C5218861 | DRV8316RRGFR | Texas Instruments | VQFN-40 5x7 mm, EP | U1 | 精确 C 号；TI RGF-40
C181596 | TLV1704AIPWR | Texas Instruments | TSSOP-14 (PW) | U2,U3 | 精确 C 号；TI PW-14
C142863 | 0454003.MR | Littelfuse | 2410 / 6125 | F1 | 官方 452/454 曲线已核
C14651 | SS56B | MDD | SMB / DO-214AA | D1 | 精确 C 号；规格匹配
C151256 | SMBJ18A | Littelfuse | SMB / DO-214AA | D2 | 精确 C 号；规格匹配
C474952 | KF128-5.08-2P-AA | KEFA | THT, P=5.08 mm | J1 (J_PWR) | 精确 5.08 mm
C474953 | KF128-5.08-3P-AA | KEFA | THT, P=5.08 mm | J2 (J_MOTOR) | 精确 5.08 mm
C55118382 | LAIL-SI-2.54-2X10P-ZC | LAILAN | THT, 2×10, P=2.54 mm | J3 (J_CTRL) | 规格与 20Pin 定义匹配
C77102 | GRM32ER71H106KA12L | Murata | 1210 | C2 | 精确 C 号；规格匹配
C28323 | CL21B105KBFNNNE | Samsung | 0805 | C3,C23 | 精确 C 号；规格匹配
C1591 | CL10B104KB8NNNC | Samsung | 0603 | C4,C5,C6,C10,C12,C21,C22 | 精确 C 号；规格匹配
C1622 | CL10B473KB8NNNC | Samsung | 0603 | C7 | 精确 C 号；规格匹配
C5673 | CL10A105KA8NNNC | Samsung | 0603 | C8,C9 | 精确 C 号；规格匹配
C45783 | CL21A226MAQNNNE | Samsung | 0805 | C11 | 精确 C 号；规格匹配
C107047 | CC0603JRNPO9BN330 | Yageo | 0603 | C13,C14,C15 | 精确 C 号；规格匹配
C14665 | CC0603JRNPO9BN101 | Yageo | 0603 | C16,C17,C18 | 精确 C 号；规格匹配
C100042 | CC0603KRX7R9BB103 | Yageo | 0603 | C19,C20,C26 | 隔离库生成通过
C1588 | CL10B102KB8NNNC | Samsung | 0603 | C24,C25 | 隔离库生成通过
C23345 | 0603WAF220JT5E | UNI-ROYAL | 0603 | R1,R14,R15 | 精确 C 号；规格匹配
C23182 | 0603WAF470JT5E | UNI-ROYAL | 0603 | R2-R7 | 精确 C 号；规格匹配
C25803 | 0603WAF1003T5E | UNI-ROYAL | 0603 | R8-R13,R19 | 精确 C 号；规格匹配
C25804 | 0603WAF1002T5E | UNI-ROYAL | 0603 | R16,R17,R18 | 精确 C 号；规格匹配
C21189 | 0603WAF0000T5E | UNI-ROYAL | 0603 | R20-R22,R39 | 精确 C 号；规格匹配
C21190 | 0603WAF1001T5E | UNI-ROYAL | 0603 | R23-R28,R36 | 精确 C 号；规格匹配
C122538 | RT0603BRD07100KL | Yageo | 0603 | R29,R32,R34,R38 | 精确 C 号；规格匹配
C2692847 | PTFR0603B21K0N9 | RESI | 0603 | R30,R31 | 精确阻值；高库存候选
C114662 | RC0603FR-072K2L | Yageo | 0603 | R33 | 隔离库生成通过
C844676 | TNPW060320K0BEEA | Vishay | 0603 | R35 | 隔离库生成通过
C855730 | AT0603BRD0723K7L | Yageo | 0603 | R37 | 精确阻值；库存偏低

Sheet: Manual_Footprints
不经过 PartsBridge 的自建封装与 40 个测试点网名
这些项目没有合适的采购 C 号：只需在 AD 中建立一次封装后复制；测试点用 0.8 mm 镀锡铜线做 U 形环。
类型 | 位号 | 网名/用途 | Qty | 建议封装名 | 几何参数 | 装配方法 | 说明
采购件人工封装 | C1 | VM bulk | 1 | CP_Radial_D12.5_P5.0_D0.9_PAD1.8 | 本体 Ø12.5 mm；引线距 5.0 mm；引线 Ø0.6 mm；成品孔 Ø0.9 mm；焊盘 Ø1.8 mm；标负极禁布区 | 采购 EEUFR1H471 / C178708；核实长脚正极、套管负极条纹后插件 | PartsBridge 源 courtyard 为畸形 SOLIDREGION；为避免坏封装，C1 不进默认 CSV
焊桥 | SJ1 | SJ_WAKE | 1 | SJ_2PAD_P1.3_NC | 2×1.2×1.5 mm SMD pad；间隙 0.20 mm；顶层 0.25 mm 铜颈默认闭合；阻焊全开 | 默认闭合；需要强制睡眠时断电后割开 | 无商品件，不进 PartsBridge
安装孔 | H1-H4 | M3 | 4 | M3_NPTH_3.2_KEEPOUT6.5 | Ø3.2 mm NPTH；所有铜层/走线/器件 keepout Ø6.5 mm | 孔边与板边、端子保持机械余量 | PCB 特征，不进 BOM 采购
测试线环 | TP1 | VM_RAW | 1 | TP_LOOP_PTH_2P_P2.54_D1.0_PAD2.0 | 同网 2×PTH；孔 Ø1.0 mm；焊盘 Ø2.0 mm；中心距 2.54 mm | 插入 0.8 mm 镀锡铜线弯 U 环，露高约 5–7 mm 后手焊 | 默认低成本方案；高 dv/dt 节点尽量短并远离模拟区
测试线环 | TP2 | VM | 1 | TP_LOOP_PTH_2P_P2.54_D1.0_PAD2.0 | 同网 2×PTH；孔 Ø1.0 mm；焊盘 Ø2.0 mm；中心距 2.54 mm | 插入 0.8 mm 镀锡铜线弯 U 环，露高约 5–7 mm 后手焊 | 默认低成本方案；高 dv/dt 节点尽量短并远离模拟区
测试线环 | TP3 | GND | 1 | TP_LOOP_PTH_2P_P2.54_D1.0_PAD2.0 | 同网 2×PTH；孔 Ø1.0 mm；焊盘 Ø2.0 mm；中心距 2.54 mm | 插入 0.8 mm 镀锡铜线弯 U 环，露高约 5–7 mm 后手焊 | 默认低成本方案；高 dv/dt 节点尽量短并远离模拟区
测试线环 | TP4 | 3V3_CTRL | 1 | TP_LOOP_PTH_2P_P2.54_D1.0_PAD2.0 | 同网 2×PTH；孔 Ø1.0 mm；焊盘 Ø2.0 mm；中心距 2.54 mm | 插入 0.8 mm 镀锡铜线弯 U 环，露高约 5–7 mm 后手焊 | 默认低成本方案；高 dv/dt 节点尽量短并远离模拟区
测试线环 | TP5 | AVDD | 1 | TP_LOOP_PTH_2P_P2.54_D1.0_PAD2.0 | 同网 2×PTH；孔 Ø1.0 mm；焊盘 Ø2.0 mm；中心距 2.54 mm | 插入 0.8 mm 镀锡铜线弯 U 环，露高约 5–7 mm 后手焊 | 默认低成本方案；高 dv/dt 节点尽量短并远离模拟区
测试线环 | TP6 | VREF | 1 | TP_LOOP_PTH_2P_P2.54_D1.0_PAD2.0 | 同网 2×PTH；孔 Ø1.0 mm；焊盘 Ø2.0 mm；中心距 2.54 mm | 插入 0.8 mm 镀锡铜线弯 U 环，露高约 5–7 mm 后手焊 | 默认低成本方案；高 dv/dt 节点尽量短并远离模拟区
测试线环 | TP7 | CP | 1 | TP_LOOP_PTH_2P_P2.54_D1.0_PAD2.0 | 同网 2×PTH；孔 Ø1.0 mm；焊盘 Ø2.0 mm；中心距 2.54 mm | 插入 0.8 mm 镀锡铜线弯 U 环，露高约 5–7 mm 后手焊 | 默认低成本方案；高 dv/dt 节点尽量短并远离模拟区
测试线环 | TP8 | CPH | 1 | TP_LOOP_PTH_2P_P2.54_D1.0_PAD2.0 | 同网 2×PTH；孔 Ø1.0 mm；焊盘 Ø2.0 mm；中心距 2.54 mm | 插入 0.8 mm 镀锡铜线弯 U 环，露高约 5–7 mm 后手焊 | 默认低成本方案；高 dv/dt 节点尽量短并远离模拟区
测试线环 | TP9 | CPL | 1 | TP_LOOP_PTH_2P_P2.54_D1.0_PAD2.0 | 同网 2×PTH；孔 Ø1.0 mm；焊盘 Ø2.0 mm；中心距 2.54 mm | 插入 0.8 mm 镀锡铜线弯 U 环，露高约 5–7 mm 后手焊 | 默认低成本方案；高 dv/dt 节点尽量短并远离模拟区
测试线环 | TP10 | FB_BK | 1 | TP_LOOP_PTH_2P_P2.54_D1.0_PAD2.0 | 同网 2×PTH；孔 Ø1.0 mm；焊盘 Ø2.0 mm；中心距 2.54 mm | 插入 0.8 mm 镀锡铜线弯 U 环，露高约 5–7 mm 后手焊 | 默认低成本方案；高 dv/dt 节点尽量短并远离模拟区
测试线环 | TP11 | SW_BK | 1 | TP_LOOP_PTH_2P_P2.54_D1.0_PAD2.0 | 同网 2×PTH；孔 Ø1.0 mm；焊盘 Ø2.0 mm；中心距 2.54 mm | 插入 0.8 mm 镀锡铜线弯 U 环，露高约 5–7 mm 后手焊 | 默认低成本方案；高 dv/dt 节点尽量短并远离模拟区
测试线环 | TP12 | INHA_DRV | 1 | TP_LOOP_PTH_2P_P2.54_D1.0_PAD2.0 | 同网 2×PTH；孔 Ø1.0 mm；焊盘 Ø2.0 mm；中心距 2.54 mm | 插入 0.8 mm 镀锡铜线弯 U 环，露高约 5–7 mm 后手焊 | 默认低成本方案；高 dv/dt 节点尽量短并远离模拟区
测试线环 | TP13 | INLA_DRV | 1 | TP_LOOP_PTH_2P_P2.54_D1.0_PAD2.0 | 同网 2×PTH；孔 Ø1.0 mm；焊盘 Ø2.0 mm；中心距 2.54 mm | 插入 0.8 mm 镀锡铜线弯 U 环，露高约 5–7 mm 后手焊 | 默认低成本方案；高 dv/dt 节点尽量短并远离模拟区
测试线环 | TP14 | INHB_DRV | 1 | TP_LOOP_PTH_2P_P2.54_D1.0_PAD2.0 | 同网 2×PTH；孔 Ø1.0 mm；焊盘 Ø2.0 mm；中心距 2.54 mm | 插入 0.8 mm 镀锡铜线弯 U 环，露高约 5–7 mm 后手焊 | 默认低成本方案；高 dv/dt 节点尽量短并远离模拟区
测试线环 | TP15 | INLB_DRV | 1 | TP_LOOP_PTH_2P_P2.54_D1.0_PAD2.0 | 同网 2×PTH；孔 Ø1.0 mm；焊盘 Ø2.0 mm；中心距 2.54 mm | 插入 0.8 mm 镀锡铜线弯 U 环，露高约 5–7 mm 后手焊 | 默认低成本方案；高 dv/dt 节点尽量短并远离模拟区
测试线环 | TP16 | INHC_DRV | 1 | TP_LOOP_PTH_2P_P2.54_D1.0_PAD2.0 | 同网 2×PTH；孔 Ø1.0 mm；焊盘 Ø2.0 mm；中心距 2.54 mm | 插入 0.8 mm 镀锡铜线弯 U 环，露高约 5–7 mm 后手焊 | 默认低成本方案；高 dv/dt 节点尽量短并远离模拟区
测试线环 | TP17 | INLC_DRV | 1 | TP_LOOP_PTH_2P_P2.54_D1.0_PAD2.0 | 同网 2×PTH；孔 Ø1.0 mm；焊盘 Ø2.0 mm；中心距 2.54 mm | 插入 0.8 mm 镀锡铜线弯 U 环，露高约 5–7 mm 后手焊 | 默认低成本方案；高 dv/dt 节点尽量短并远离模拟区
测试线环 | TP18 | SCK_DRV | 1 | TP_LOOP_PTH_2P_P2.54_D1.0_PAD2.0 | 同网 2×PTH；孔 Ø1.0 mm；焊盘 Ø2.0 mm；中心距 2.54 mm | 插入 0.8 mm 镀锡铜线弯 U 环，露高约 5–7 mm 后手焊 | 默认低成本方案；高 dv/dt 节点尽量短并远离模拟区
测试线环 | TP19 | MOSI_DRV | 1 | TP_LOOP_PTH_2P_P2.54_D1.0_PAD2.0 | 同网 2×PTH；孔 Ø1.0 mm；焊盘 Ø2.0 mm；中心距 2.54 mm | 插入 0.8 mm 镀锡铜线弯 U 环，露高约 5–7 mm 后手焊 | 默认低成本方案；高 dv/dt 节点尽量短并远离模拟区
测试线环 | TP20 | CS_N | 1 | TP_LOOP_PTH_2P_P2.54_D1.0_PAD2.0 | 同网 2×PTH；孔 Ø1.0 mm；焊盘 Ø2.0 mm；中心距 2.54 mm | 插入 0.8 mm 镀锡铜线弯 U 环，露高约 5–7 mm 后手焊 | 默认低成本方案；高 dv/dt 节点尽量短并远离模拟区
测试线环 | TP21 | DRVOFF | 1 | TP_LOOP_PTH_2P_P2.54_D1.0_PAD2.0 | 同网 2×PTH；孔 Ø1.0 mm；焊盘 Ø2.0 mm；中心距 2.54 mm | 插入 0.8 mm 镀锡铜线弯 U 环，露高约 5–7 mm 后手焊 | 默认低成本方案；高 dv/dt 节点尽量短并远离模拟区
测试线环 | TP22 | nSLEEP | 1 | TP_LOOP_PTH_2P_P2.54_D1.0_PAD2.0 | 同网 2×PTH；孔 Ø1.0 mm；焊盘 Ø2.0 mm；中心距 2.54 mm | 插入 0.8 mm 镀锡铜线弯 U 环，露高约 5–7 mm 后手焊 | 默认低成本方案；高 dv/dt 节点尽量短并远离模拟区
测试线环 | TP23 | nFAULT/HARD_FAULT_N | 1 | TP_LOOP_PTH_2P_P2.54_D1.0_PAD2.0 | 同网 2×PTH；孔 Ø1.0 mm；焊盘 Ø2.0 mm；中心距 2.54 mm | 插入 0.8 mm 镀锡铜线弯 U 环，露高约 5–7 mm 后手焊 | 默认低成本方案；高 dv/dt 节点尽量短并远离模拟区
测试线环 | TP24 | SOA_RAW | 1 | TP_LOOP_PTH_2P_P2.54_D1.0_PAD2.0 | 同网 2×PTH；孔 Ø1.0 mm；焊盘 Ø2.0 mm；中心距 2.54 mm | 插入 0.8 mm 镀锡铜线弯 U 环，露高约 5–7 mm 后手焊 | 默认低成本方案；高 dv/dt 节点尽量短并远离模拟区
测试线环 | TP25 | SOB_RAW | 1 | TP_LOOP_PTH_2P_P2.54_D1.0_PAD2.0 | 同网 2×PTH；孔 Ø1.0 mm；焊盘 Ø2.0 mm；中心距 2.54 mm | 插入 0.8 mm 镀锡铜线弯 U 环，露高约 5–7 mm 后手焊 | 默认低成本方案；高 dv/dt 节点尽量短并远离模拟区
测试线环 | TP26 | SOC_RAW | 1 | TP_LOOP_PTH_2P_P2.54_D1.0_PAD2.0 | 同网 2×PTH；孔 Ø1.0 mm；焊盘 Ø2.0 mm；中心距 2.54 mm | 插入 0.8 mm 镀锡铜线弯 U 环，露高约 5–7 mm 后手焊 | 默认低成本方案；高 dv/dt 节点尽量短并远离模拟区
测试线环 | TP27 | SOA_FANOUT | 1 | TP_LOOP_PTH_2P_P2.54_D1.0_PAD2.0 | 同网 2×PTH；孔 Ø1.0 mm；焊盘 Ø2.0 mm；中心距 2.54 mm | 插入 0.8 mm 镀锡铜线弯 U 环，露高约 5–7 mm 后手焊 | 默认低成本方案；高 dv/dt 节点尽量短并远离模拟区
测试线环 | TP28 | SOB_FANOUT | 1 | TP_LOOP_PTH_2P_P2.54_D1.0_PAD2.0 | 同网 2×PTH；孔 Ø1.0 mm；焊盘 Ø2.0 mm；中心距 2.54 mm | 插入 0.8 mm 镀锡铜线弯 U 环，露高约 5–7 mm 后手焊 | 默认低成本方案；高 dv/dt 节点尽量短并远离模拟区
测试线环 | TP29 | SOC_FANOUT | 1 | TP_LOOP_PTH_2P_P2.54_D1.0_PAD2.0 | 同网 2×PTH；孔 Ø1.0 mm；焊盘 Ø2.0 mm；中心距 2.54 mm | 插入 0.8 mm 镀锡铜线弯 U 环，露高约 5–7 mm 后手焊 | 默认低成本方案；高 dv/dt 节点尽量短并远离模拟区
测试线环 | TP30 | SOA_ADC | 1 | TP_LOOP_PTH_2P_P2.54_D1.0_PAD2.0 | 同网 2×PTH；孔 Ø1.0 mm；焊盘 Ø2.0 mm；中心距 2.54 mm | 插入 0.8 mm 镀锡铜线弯 U 环，露高约 5–7 mm 后手焊 | 默认低成本方案；高 dv/dt 节点尽量短并远离模拟区
测试线环 | TP31 | SOB_ADC | 1 | TP_LOOP_PTH_2P_P2.54_D1.0_PAD2.0 | 同网 2×PTH；孔 Ø1.0 mm；焊盘 Ø2.0 mm；中心距 2.54 mm | 插入 0.8 mm 镀锡铜线弯 U 环，露高约 5–7 mm 后手焊 | 默认低成本方案；高 dv/dt 节点尽量短并远离模拟区
测试线环 | TP32 | SOC_ADC | 1 | TP_LOOP_PTH_2P_P2.54_D1.0_PAD2.0 | 同网 2×PTH；孔 Ø1.0 mm；焊盘 Ø2.0 mm；中心距 2.54 mm | 插入 0.8 mm 镀锡铜线弯 U 环，露高约 5–7 mm 后手焊 | 默认低成本方案；高 dv/dt 节点尽量短并远离模拟区
测试线环 | TP33 | V_LOW | 1 | TP_LOOP_PTH_2P_P2.54_D1.0_PAD2.0 | 同网 2×PTH；孔 Ø1.0 mm；焊盘 Ø2.0 mm；中心距 2.54 mm | 插入 0.8 mm 镀锡铜线弯 U 环，露高约 5–7 mm 后手焊 | 默认低成本方案；高 dv/dt 节点尽量短并远离模拟区
测试线环 | TP34 | V_HIGH | 1 | TP_LOOP_PTH_2P_P2.54_D1.0_PAD2.0 | 同网 2×PTH；孔 Ø1.0 mm；焊盘 Ø2.0 mm；中心距 2.54 mm | 插入 0.8 mm 镀锡铜线弯 U 环，露高约 5–7 mm 后手焊 | 默认低成本方案；高 dv/dt 节点尽量短并远离模拟区
测试线环 | TP35 | VBUS_DIV_RAW | 1 | TP_LOOP_PTH_2P_P2.54_D1.0_PAD2.0 | 同网 2×PTH；孔 Ø1.0 mm；焊盘 Ø2.0 mm；中心距 2.54 mm | 插入 0.8 mm 镀锡铜线弯 U 环，露高约 5–7 mm 后手焊 | 默认低成本方案；高 dv/dt 节点尽量短并远离模拟区
测试线环 | TP36 | VBUS_SENSE | 1 | TP_LOOP_PTH_2P_P2.54_D1.0_PAD2.0 | 同网 2×PTH；孔 Ø1.0 mm；焊盘 Ø2.0 mm；中心距 2.54 mm | 插入 0.8 mm 镀锡铜线弯 U 环，露高约 5–7 mm 后手焊 | 默认低成本方案；高 dv/dt 节点尽量短并远离模拟区
测试线环 | TP37 | VBUS_TRIP | 1 | TP_LOOP_PTH_2P_P2.54_D1.0_PAD2.0 | 同网 2×PTH；孔 Ø1.0 mm；焊盘 Ø2.0 mm；中心距 2.54 mm | 插入 0.8 mm 镀锡铜线弯 U 环，露高约 5–7 mm 后手焊 | 默认低成本方案；高 dv/dt 节点尽量短并远离模拟区
测试线环 | TP38 | OUTA | 1 | TP_LOOP_PTH_2P_P2.54_D1.0_PAD2.0 | 同网 2×PTH；孔 Ø1.0 mm；焊盘 Ø2.0 mm；中心距 2.54 mm | 插入 0.8 mm 镀锡铜线弯 U 环，露高约 5–7 mm 后手焊 | 默认低成本方案；高 dv/dt 节点尽量短并远离模拟区
测试线环 | TP39 | OUTB | 1 | TP_LOOP_PTH_2P_P2.54_D1.0_PAD2.0 | 同网 2×PTH；孔 Ø1.0 mm；焊盘 Ø2.0 mm；中心距 2.54 mm | 插入 0.8 mm 镀锡铜线弯 U 环，露高约 5–7 mm 后手焊 | 默认低成本方案；高 dv/dt 节点尽量短并远离模拟区
测试线环 | TP40 | OUTC | 1 | TP_LOOP_PTH_2P_P2.54_D1.0_PAD2.0 | 同网 2×PTH；孔 Ø1.0 mm；焊盘 Ø2.0 mm；中心距 2.54 mm | 插入 0.8 mm 镀锡铜线弯 U 环，露高约 5–7 mm 后手焊 | 默认低成本方案；高 dv/dt 节点尽量短并远离模拟区

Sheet: Selection_Notes
选型结论、PartsBridge 0.3.7 导入步骤与真实限制
默认参数已冻结到验证板首版；有实物后只调整电流窗口、VBUS 阈值、RC 和热设计，不重新发明代码/接口架构。
主题 | 已冻结决定 | 理由/证据 | 你在 AD/采购时要做什么 | 依据/链接
版本绑定 | 只针对 PartsBridge AD 0.3.7 | 已读取实际交付目录 README/WINDOWS_RELEASE；确认版本 0.3.7.0。 | 使用 G:\Agent\deliverables\partsbridge-v0.3.7\PartsBridge-AD\PartsBridge-AD.exe | 本机交付包
CSV 规则 | 默认导入文件仅一列 lcsc | 0.3.7 接受首列或 lcsc/product_code/code；UTF-8 BOM 可直接识别。 | 在界面点击“导入已确认 C 编号 CSV”，选择本目录 *_PartsBridge_Import.csv。 | PartsBridge 0.3.7 README §批量 CSV
使用顺序 | 导入→核对队列→追加到总库 | PartsBridge 只追加 LCSC.SchLib/LCSC.PcbLib，不会替你把器件放进原理图。 | 先在 AD 保存并关闭两份库；PartsBridge 与 AD 使用相同权限；再点“追加到总库”。 | PartsBridge 0.3.7 README §最快开始
关键保护 | F1=0454003.MR / C142863 | 官方 452/454 系列为 Slo-Blo；3 A 名义熔断 I²t=20.16 A²s（8 ms），能比快断件更耐浪涌。 | 首板仍用限流电源缓升；不得把保险丝当半导体 OCP。 | https://www.littelfuse.com/assetdocs/fuse-452-and-454-datasheet?assetguid=8c87aa93-80a7-4ea8-8749-a19ba03901c2
关键 IC | U2/U3 选 TLV1704AIPWR | PWR 是卷带包装后缀；TI 同时列出 AIPW 与 AIPWR，均为 PW/TSSOP-14。 | 原理图 Value 可写 TLV1704AIPW；采购 MPN/LCSC 用 TLV1704AIPWR/C181596。 | https://www.ti.com/product/TLV1704/part-details/TLV1704AIPWR
关键 IC | U1=DRV8316RRGFR | TI 确认为 RGF、VQFN-40、5×7 mm、0.5 mm pitch。 | PartsBridge 导入后仍按 TI datasheet 逐脚核符号、EP41、Pin1、钢网窗和热过孔。 | https://www.ti.com/lit/ds/symlink/drv8316.pdf
连接器 | J1/J2 固化为 KF128 5.08 mm | 不是近似 5.0 mm；24 A 额定为验证板留出接线和温升余量。 | 按导入封装核 1 脚、开口朝板外和螺丝刀空间。 | C474952 / C474953
测试点 | 40 个测试点默认自制 0.8 mm 镀锡线环 | 商业 Keystone 5015/C2906768 单价约 ¥1.69，40 个约 ¥68 且挤占 70×55 mm 板面。 | 按 Manual_Footprints 页建一个通用 PTH 线环封装，复制并逐一标网名。 | 可选件 C2906768，不进入默认导入 CSV
人工封装 | C1 保留采购 C178708，但不进默认 CSV | Panasonic 官方尺寸为 Ø12.5×20 mm、P=5.0 mm、引线 Ø0.6 mm；PartsBridge 源 CAD 的 courtyard 为畸形 SOLIDREGION。 | 按 Manual_Footprints 页尺寸手建极性电解封装；不要换成自动导入的畸形封装。 | https://industrial.panasonic.com/ww/products/pt/aluminum-cap-lead/models/EEUFR1H471
精密分压 | R37 的 23.7 kΩ 库存偏低 | C855730 快照库存 93，足够首板但可能波动。 | 下单前复查；缺货可用同值同封装 0.1% 的 C3919228，仍需在原理图和 BOM 同步替换。 | 价格/库存快照 2026-08-30
编码器边界 | AS5048A 不在本验证子板 BOM | 本板验证 DRV8316R 功率级、CSA、比较器、VBUS 和控制头；电机内编码器通过主控侧单独接入。 | 不要在本板上额外加 AS5048A 接口，避免改变当前已锁架构。 | SCHEMATIC_PCB_DRAWING_GUIDE_CN.md
成本口径 | 装板物料合计不含 PCB/运费/税/工装 | 测试点线环与安装孔按 0 元计；建议采购数只是备料建议，成本公式按每板实际数量。 | 以 Line CNY 合计作为 1 块板的元器件快照估算。 | 价格/库存快照 2026-08-30
本轮校验 | 29/29 默认导入 C 号已在隔离临时库生成符号/封装；C1 因源 CAD courtyard 畸形改为人工封装 | 结构校验与临时建库结果记录在这里；这不等于 Altium GUI 中已完成人工封装/引脚验收。 | 最终仍要在 AD 中对每个关键器件执行 datasheet 复核。 | 本地验证

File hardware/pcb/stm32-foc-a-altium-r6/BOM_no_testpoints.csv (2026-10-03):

Reference | Value | MPN | Package | Fitted | Note | Source_KiCad_Footprint | Source_footprint_selection | Altium_PCB_Model | Altium_PCB_Library | User_Library_Source | Model_match_basis
U1 | STM32G474CET6 | STM32G474CET6 | LQFP48 7×7 mm，0.5 mm | 1 | 必须选CET6；不是NUCLEO上的RET6 | GL30:LQFP-48_7x7mm_P0.5mm | selected - verify | QFP50P900X900X160-48N | User_SamacSys.PcbLib | G:\dontdel\AD_Lib\SamacSys.PcbLib | Exact Manufacturer_Part_Number parameter and exact record-45 ModelName/ModelDatafileEntity0 in the new native SchLib. 48 pads and 0.5 mm pitch; numbering is a rotated equivalent of the ST top-view drawing. Lands are 1.475 x 0.3 mm versus ST example 1.2 x 0.3 mm; the longer user-library lands are retained.
U2 | DRV8316RRGFR | DRV8316RRGFR | RGF VQFN40 7×5 mm + EP | 1 | R版SPI；每个VM脚配2颗100n；裸露焊盘必须接地 |  | pending | C5218861_VQFN-40_5x7 | User_LCSC.PcbLib | G:\dontdel\AD\_Lib\LCSC.PcbLib | SchLib parameter MPN=DRV8316RRGFR and LCSC=C5218861; symbol record 45 ModelName points to the exact PcbLib footprint; no MPN substitution. TI RGF0040E checked: 40 perimeter lands, 0.5 mm pitch, 0.6 x 0.25 mm lands; row-center spans 4.8 and 6.8 mm; EP41 3.7 x 5.7 mm. Ground pin retained. Thermal vias and stencil design remain PCB tasks.
U3 | TLV1704AIPWR | TLV1704AIPWR | PW TSSOP14 5×4.4 mm | 1 |  | GL30:TSSOP-14_4.4x5mm_P0.65mm | selected - verify | C181596_TSSOP-14 | User_LCSC.PcbLib | G:\dontdel\AD\_Lib\LCSC.PcbLib | SchLib parameter MPN=TLV1704AIPWR and LCSC=C181596; exact symbol model record links to C181596_TSSOP-14.
U4 | TLV1704AIPWR | TLV1704AIPWR | PW TSSOP14 5×4.4 mm | 1 | 仅U4通道4未用：+接AVDD，−接GND，输出NC；U3四路全用 | GL30:TSSOP-14_4.4x5mm_P0.65mm | selected - verify | C181596_TSSOP-14 | User_LCSC.PcbLib | G:\dontdel\AD\_Lib\LCSC.PcbLib | SchLib parameter MPN=TLV1704AIPWR and LCSC=C181596; exact symbol model record links to C181596_TSSOP-14.
U5 | TLV75533PDBVR | TLV75533PDBVR | DBV SOT-23-5 | 1 | 原B板B10不删除；本板3V3禁止与B/ESP的独立3V3并联 | GL30:SOT-23-5 | selected - verify | SOT95P280X145-5N | User_SamacSys.PcbLib | G:\dontdel\AD_Lib\SamacSys.PcbLib | TI DBV0005A: five pins, 0.95 mm pitch, standard 1/2/3 left and 4/5 right numbering. Library copper 1.2 x 0.6 mm, row centers 2.5 mm. Different source symbol MPN is not a procurement replacement.
U6 | SN74LVC1G07DBVR | SN74LVC1G07DBVR | DBV SOT-23-5 | 1 | 防止比较器反拉DRV物理nFAULT | GL30:SOT-23-5 | selected - verify | SOT95P280X145-5N | User_SamacSys.PcbLib | G:\dontdel\AD_Lib\SamacSys.PcbLib | TI DBV0005A: five pins, 0.95 mm pitch, standard 1/2/3 left and 4/5 right numbering. Library copper 1.2 x 0.6 mm, row centers 2.5 mm. Different source symbol MPN is not a procurement replacement.
U7 | SN74LVC1G07DBVR | SN74LVC1G07DBVR | DBV SOT-23-5 | 1 | 由ESP域供电；输入100k下拉；STM失电时报告故障 | GL30:SOT-23-5 | selected - verify | SOT95P280X145-5N | User_SamacSys.PcbLib | G:\dontdel\AD_Lib\SamacSys.PcbLib | TI DBV0005A: five pins, 0.95 mm pitch, standard 1/2/3 left and 4/5 right numbering. Library copper 1.2 x 0.6 mm, row centers 2.5 mm. Different source symbol MPN is not a procurement replacement.
U8 | TXU0202DCUR | TXU0202DCUR | DCU VSSOP8 2.3×2.0 mm | 1 | 一发一收固定方向；不是TXB0102；OE接3V3 | GL30:VSSOP-8_2.3x2mm_P0.5mm | selected - verify | SOP50P310X90-8N | User_SamacSys.PcbLib | G:\dontdel\AD_Lib\SamacSys.PcbLib | TI DCU0008A: 8 pins, 0.5 mm pitch, body 2.3 x 2.0 mm, lead span 3.1 mm. Library copper 0.85 x 0.3 mm, row centers 3.15 mm, standard counterclockwise numbering.
U9 | TMUX1511PWR | TMUX1511PWR | PW TSSOP14 5×4.4 mm | 1 | 4路SEL均接3V3；断电保护信号≤3.6V；保持比较器支路直连 | GL30:TSSOP-14_4.4x5mm_P0.65mm | selected - verify | SOP65P640X120-14N | User_SamacSys.PcbLib | G:\dontdel\AD_Lib\SamacSys.PcbLib | TI PW0014A: 14 pins, 0.65 mm pitch, body 4.4 x 5.0 mm; 6.4 mm in library name is lead span, not body width. Library copper 1.475 x 0.45 mm, row centers 5.876 mm, matches standard PW pin order; retain purchased IC symbols.
R1 | 0 Ω跳线；0.1 W | 通用0Ω跳线 0.1 W | 0603 | 1 |  | GL30:R_0603_1608Metric | selected - verify | R0603_M | User_STM32F407_Ctrl.PcbLib | G:\dontdel\AD_Lib\STM32F407_Ctrl.PcbLib | SchLib R symbol explicitly offers R0603_M; 2 pads, pad 1 left/pad 2 right, body outline about 1.70 x 0.80 mm.
R2 | 0 Ω跳线；0.125 W | 通用0Ω跳线 0.125 W | 0805 | 1 | 0805磁珠兼容焊盘；首装0Ω，不将模拟地割裂 | GL30:R_0805_2012Metric | selected - verify | R0805_M | User_STM32F407_Ctrl.PcbLib | G:\dontdel\AD_Lib\STM32F407_Ctrl.PcbLib | SchLib R symbol explicitly offers R0805_M; 2 pads, pad 1 left/pad 2 right, body outline about 2.30 x 1.35 mm.
R3 | 0 Ω跳线；0.1 W | 通用0Ω跳线 0.1 W | 0603 | 1 | 可拆以单独测B/C传感器电流 | GL30:R_0603_1608Metric | selected - verify | R0603_M | User_STM32F407_Ctrl.PcbLib | G:\dontdel\AD_Lib\STM32F407_Ctrl.PcbLib | SchLib R symbol explicitly offers R0603_M; 2 pads, pad 1 left/pad 2 right, body outline about 1.70 x 0.80 mm.
R4 | 10k Ω；1%；0.1 W | 通用厚膜 10k 1% 0.1 W | 0603 | 1 |  | GL30:R_0603_1608Metric | selected - verify | R0603_M | User_STM32F407_Ctrl.PcbLib | G:\dontdel\AD_Lib\STM32F407_Ctrl.PcbLib | SchLib R symbol explicitly offers R0603_M; 2 pads, pad 1 left/pad 2 right, body outline about 1.70 x 0.80 mm.
R5 | 100k Ω；1%；0.1 W | 通用厚膜 100k 1% 0.1 W | 0603 | 1 |  | GL30:R_0603_1608Metric | selected - verify | R0603_M | User_STM32F407_Ctrl.PcbLib | G:\dontdel\AD_Lib\STM32F407_Ctrl.PcbLib | SchLib R symbol explicitly offers R0603_M; 2 pads, pad 1 left/pad 2 right, body outline about 1.70 x 0.80 mm.
R6 | 0 Ω跳线；0.1 W | 通用0Ω跳线 0.1 W | 0603 | 1 | 晶体驱动调试位置，首装0Ω | GL30:R_0603_1608Metric | selected - verify | R0603_M | User_STM32F407_Ctrl.PcbLib | G:\dontdel\AD_Lib\STM32F407_Ctrl.PcbLib | SchLib R symbol explicitly offers R0603_M; 2 pads, pad 1 left/pad 2 right, body outline about 1.70 x 0.80 mm.
R7 | 2.2k Ω；1%；0.1 W | 通用厚膜 2.2k 1% 0.1 W | 0603 | 1 |  | GL30:R_0603_1608Metric | selected - verify | R0603_M | User_STM32F407_Ctrl.PcbLib | G:\dontdel\AD_Lib\STM32F407_Ctrl.PcbLib | SchLib R symbol explicitly offers R0603_M; 2 pads, pad 1 left/pad 2 right, body outline about 1.70 x 0.80 mm.
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

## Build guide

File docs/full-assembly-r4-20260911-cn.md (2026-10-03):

# GL30 R4 整机内部布置

2026-09-11。此版补上 R3 核心模型遗漏的电路板、电池、侧键、电源键和安装/走线空间。R3 不能再作为“整体模型”交付；本页是当前整机布置入口。

后续取舍复核见[皮带手感与机构简化](belt-feel-and-simplification-20260911-cn.md)：R4 未验证皮带对触觉的影响，不能当成直驱同等手感；中心通道的堵件身份仍未确认，不能直接归因于编码器。

## 先看模型

- [完整装配 STEP](../output/models/GL30_FULL_R4/GL30_FULL_R4_ASSEMBLY.step)
- [中文标注内部布置图](../output/models/GL30_FULL_R4/annotated_internal_layout.png)
- [中文分组爆炸图](../output/models/GL30_FULL_R4/annotated_exploded_groups.png)
- [外壳透明图](../output/models/GL30_FULL_R4/transparent.png)
- [几何检查记录](../output/models/GL30_FULL_R4/verification.json)
- [最终 STEP 读回记录](../output/models/GL30_FULL_R4/step_readback.json)
- [线束与按键座接触复核](../output/models/GL30_FULL_R4/routing_contact_review.json)
- [单套电子器件和连接器 BOM](../outputs/01a08963-e2d7-71e2-a353-8710a44dc948/bom-cost-down/GL30_单套降本BOM_20260911.xlsx)

这是整机**空间布置模型**：A/B/C 板框和主要器件包络、完整显示模组、原厂电机编码器、电池目标包络、七个开关及主要机构均已纳入。A/B/C 尚未完成原理图位号展开、焊盘布局及布线，不是可直接制板/开模的定版文件。线束显示通道及服务空间，最终折弯、夹持和所有线端尚未完成装配定型。

## 电路板、按钮、电池分别在哪里

| 标记 | 零件 | 布置及用途 |
|---|---|---|
| A，绿色 | STM32 电机控制板 | 后部下层，板底 Z=29.2 mm；包括驱动、比较器、SWD、复位及旋环按压开关。前侧切口避让倾斜电机。 |
| B，蓝色 | 电源和接口板 | 后部上层，板底 Z=44 mm；两面利用，放 PD、充电、保护、两路降压和制动控制。左侧两个缺口避让按键座。 |
| C，环形 | 固定 LED 板 | 旋环根部，24 只 2020 LED 包络，主环外径 66、内径 58 mm；连接器在侧耳背面。外面仍是连续扩散窗口。 |
| D | 完整 Waveshare 显示模组 | 位于旋环中央的固定托盘，保留供应商模型中的显示板、元件和连接器，未拆成裸 AMOLED。 |
| E | GL30＋原厂编码器 | 旋钮左下方，原厂编码器仍保留；用短同步带驱动中空旋转轴。 |
| F，橙色 | 定制 3S 电池包 | 前下方横置，利用倾斜面板下方的空腔。目标外形包含保护/均衡、NTC、绝缘，容量及电流由厂家确认。 |
| 左右侧 | 四个侧键 | 每侧两个；恢复实际键帽、开关包络和绝缘固定座。单套打样按键可在固定座内转向安装并接线，避免额外增加四块刚性小板。 |
| 后侧 | 电源键、USB-C | 电源键有开关和固定座；USB-C 从上层 B 板朝后引出。 |

七只新增轻触开关的计数为：四侧键＋后电源键＋旋环按压＋A 板复位。显示模组原本自带的 PWR/BOOT 器件包含在 D 的原厂总成内，不再重复购买。复位键位于内部 A 板，拆开后维护使用。

## 为何是这样的传动和固定方式

原厂 STEP 中未确认可贯通的固定屏柱通道，且图纸孔径不等于带编码器总成的可用净空。R4 为避免依赖未确认的通道，采用左侧电机和短同步带驱动中央中空轴；固定屏柱从中空轴内部穿过并落到底板，屏幕不随外圈转，外面没有屏幕桥架。这是空间布置上的折中，不代表皮带是唯一可行方案，也不能把 STEP 中的堵件直接认定为编码器。

旋环、转轴、轴承座、电机和皮带随按压平台一起移动；MGN7 型导向包络约束平台姿态。R4 把原来互不相接的底座和支撑肋合成连续承力件，并补入导轨落地支撑、三处回弹/限位、轴承压盖和按压触发片。上部轴承与同步轮之间留出间隙，压盖和内圈垫圈分开表示。

按压目标行程仍为 0.35 mm。SKRPASE010 的开关工作行程与平台总行程不能等同；触发片预留空行程和少量柔性余量，硬限位由机构承担。弹簧刚度、预压、导轨实际间隙和触发片寿命尚未通过样机验证，不能据 CAD 承诺“不晃动”或最终手感。

本轮还纠正了旧代码的显示模组方向。原厂 STEP 的 TP 层位于 local Y=0…1.3 mm，LCD、PCBA 和背面器件向 −Y 延伸；R4 将 local +Y 朝向用户。原供应商文件保持只读，导出时重建其 403 个有效独立实体的组合；不再用黑色圆片代替整块模组。

## 空间如何利用

- 机壳外形 **104×98 mm**，后部壳高 62 mm，包含旋钮及脚垫的总高度约 **80.7 mm**。四角收圆，没有为加入电池和电路板继续加宽外壳。
- 相比之前 118×114 mm 的三板方案，占地减少约 **24.2%**；相比缺件的 R3 104×100 mm，又缩短 2 mm。宽度受左侧原厂电机和右侧旋环/导向间隙限制，不是任意留出的空盒。
- 电池目标 **74×24×21 mm**；安装及膨胀预留包络 **78×28×23.5 mm**。采用常规长条形组合，避免难加工的环形或极端异形电芯。固定端座和底部缓冲定位电池，不用按压载荷挤压电芯大面。
- A/B 板最大外包络约 **73.5×26×1.2 mm**，采用电机缺口、侧键缺口和走线缺口；B 板背面也利用了板间空间。具体外形以各 STEP/DXF 为准。
- 普通信号用两条 FFC；电池、电机和 LED 主功率保留独立导线及 XT30，不能让普通细间距 FFC 承担电机电流。

这里是按当前硬件和可装配余量优化后的布置，不宣称获得数学意义的最高填充率。电池容量、散热、接头拔插及 PCB 布线都可能要求修正局部空间。

## 本版文件检查

源模型共 156 个命名部件组，包含完整显示模组的 403 个有效独立实体。主几何检查的 10 项均通过，覆盖三块自定义板、七只开关、24 只 LED、连成单实体的按压支架、选定电子件与电池空间、0/0.175/0.35 mm 三档按压位置，以及中央旋转件的整周扫掠包络。

对线束、接头及按键座另扫描 2726 对部件。最终 12 处正体积接触逐项核对为：四个侧键座与外壳一体连接的安装舌片，以及八处导线/FFC 进入各自接插件或焊接区。这个计数不代表整机所有实体两两均有间隙：回弹簧采用可压缩包络，硬限位在行程末端应接触；同束导线的实际分线和弯曲细节仍未定型。

最终 STEP 经重新读取，632 个实体有效，包络为 X[-52,52]、Y[-49,49]、Z[-1.2,79.489938] mm；交付包含读回记录及文件 SHA256。上述检查属于几何证据，不替代强度、装配工艺、线路设计或实物测试。

## 当前还没有定型的实物项

1. 电机定子固定孔/夹持面、同步轮齿形与紧固、公差、轴承压盖螺钉和轴向预紧需要继续细化。模型中的采购件包络不代替原厂安装图。
2. FFC 的最终折线、剩余长度收纳、所有插头的拔插路线和固定屏柱内完整线束尚需样件验证。模型中的线束是通道表示，不能把它当作已通过弯曲寿命和装配试验。
3. 扬声器已预留 20×14×4 mm 空间并补入 BOM 的待选项。官方模组提供外接扬声器接口，具体扬声器并未在此前清单中选定。[Waveshare 官方接口说明](https://docs.waveshare.com/ESP32-S3-Touch-AMOLED-1.32)
4. 内置制动热模块预留 26×12×9 mm；原 HSA2510RJ 仍是台架负载，不装进此处。内置型号、回灌能量和封闭温升尚未验收。

本轮只进行了文件、几何与采购表一致性工作，未烧录、通电、打印或操作真实电机。

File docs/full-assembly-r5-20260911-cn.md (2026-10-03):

# GL30 R5：短同步带、收腰旋钮与装配简化

2026-09-11。用户已确认电机没有可用的中心通道。本版保留偏置电机和隐藏的固定屏柱，不增加外置屏幕支架。外形约 **104 × 98 × 80.18 mm**（含脚垫与旋钮）。这是可检查的机械布置模型，电机安装接口、公差和实物手感尚未定版。

## 模型与图

- [整机 STEP，简化板上器件](../output/models/GL30_FULL_R5/GL30_FULL_R5_ASSEMBLY.step)
- [外观图](../output/models/GL30_FULL_R5/exterior_r5.png) · [内部布置图](../output/models/GL30_FULL_R5/internal_layout_r5.png)
- [几何检查](../output/models/GL30_FULL_R5/verification.json) · [STEP 回读](../output/models/GL30_FULL_R5/step_readback.json)
- [灯圈真实剖面](../output/models/GL30_FULL_R5/light_ring_section_r5.png) · [内部机械复核](../output/models/GL30_FULL_R5/independent-mechanics.json)
- [单套机械件预算及来源](../outputs/01a08963-e2d7-71e2-a353-8710a44dc948/r5-review/mechanical-cost-evidence.md)

## 本次修改

| 用户关心的问题 | R5 实际修改 | 仍需实物确认 |
| --- | --- | --- |
| 反转出现间隙感 | 保留 36∶36 齿、2 mm 节距、6 mm 宽短闭环同步带；名义周长 156 mm；电机沿中心距方向调节后用两颗螺钉锁住 | 同厂家带与轮匹配、齿隙、带轮与轴连接、实际张力 |
| 支撑刚度 | 承力架主体底板由 2 增至 3 mm，编码器下方仍保留避让；两条筋由 4×4 改为 5×5 mm；轴承中心跨度由 11 增至 13 mm | 金属加工、公差、导轨游隙与偏心按压下的晃动 |
| 灯圈附近露缝 | 握持圈增加 1.2 mm 厚下垂裙边，与固定遮光边重叠；外缘盖边遮住原开孔接缝 | 全公差下无擦碰；光学均匀度 |
| 旋钮变成直筒 | 恢复 `compact_knob.py` R2 的收腰和圆肩外轮廓，高握持圈保留 | 表面处理、最终触感 |
| 过多小支座 | 机壳实际合并四侧键固定座、灯板上侧安装柱和遮光结构；底盖实际合并三弹簧座、两个电池定位座 | 打印工艺与小螺孔加工 |
| PCB 看起来太复杂 | 交付 STEP 保留板框、固定孔、机械接口、按钮和线束；隐藏 IC、电感、电容和单颗 LED，屏模组仅保留主要层 | 这是显示简化，原安装空间仍用于检查，不能压缩元件所需高度 |

带轮已补入挡边空间，而不是继续使用只有 6 mm 厚的无挡边圆柱。挡边加入后发现过一次灯板/壳体干涉，本版已下移传动层并增加壳体内侧避让。挡边外径 27 mm、总轴向包络 7.6 mm；仍为定制低矮带轮的空间要求，不是某个厂家成品的完整制造图。

## 同步带选型和“零间隙”的边界

本版选用同一供方确认齿形匹配的 **2GT 闭环带 + 精密金属带轮**。156 mm 周长对应 78 个带齿，36T 是每只带轮的齿数。中心距名义值 42 mm，装配调节范围 41.5–42.5 mm；几何范围不是张力设定值，装好后需要测量并锁紧。当前不增加弹性张紧轮。

低回差的成熟产品确实存在，例如 NBK 的 P36-2GT-BLP-6C，厂家声明单齿回差为零。但其标准孔只有 3–6 mm、总宽 10.3 mm，而且每只目录未税价 5,480 日元；不能直接替代本版的 12 mm 输出孔、低矮包络，也不能把这一性能转移给普通低价轮。[NBK 官方规格与价格](https://www.nbk1560.com/products/pulley/timingpulley/2GT-BLP-6C/P36-2GT-BLP-6C/)

带体伸长、齿部变形及连接件柔度仍会产生加载转角。过分预紧会增加轴承负荷和摩擦，不能靠“拉得越紧越好”解决。[Gates 精密传动手册](https://www.gates.com/content/dam/documents-library/catalogs/light-power-and-precision-manual.pdf)

单套样机建议分别记录：低速正反转的空行程、±0.060 N·m 下的加载转角与卸载迟滞、无电时的起动阻力、中心和偏心按压的晃动。初始评估目标可取反转空行程 ≤0.2°、0.060 N·m 下弹性转角 ≤0.5°；这是验收目标，不是已达到的参数，也不是新的电机操作许可。原厂电机侧编码器不能独立测出带后的变形，可用临时外部角度测量或力臂/位移表验收。

## 灯圈与装配顺序

遮光裙的名义径向间隙 **0.4 mm**；静止时轴向重叠 **1.7 mm**，按到底 0.35 mm 后重叠 **2.05 mm**。这里保留运动间隙，通过遮挡使内部不可直视，不把两件做成接触摩擦。

灯窗开口径向宽 **1.6 mm**，独立乳白光导为 Ø67.0 / Ø64.2 × 0.9 mm 的连续直环，两侧各留名义 0.1 mm 装配间隙。从顶部放入并在隐藏支撑处用薄胶点固定，可在拆下握持圈后取出。CAD 使用不透明奶白颜色表达扩散件；没有完成光线仿真或实物均匀度测试，不能因此保证看不出热点。

灯板改为从底部顶到三处上侧安装柱，用三颗 M1.6×4 固定。孔位在 LED 间隙并避开电机带轮。取消原来的下托耳，避免板子被上方遮光结构困住。PCB C 的机械 DXF 已同步增加三个孔，铜箔布局尚未完成。

装配按下列模块进行，不把所有小件一开始都塞进壳内：

1. 壳体倒置，先放四侧键与后电源键，再从底部装灯板及排线。
2. 预装金属承力架、双轴承、旋钮轴、同步轮、同步带和电机滑座；调整张力后锁紧。
3. 安装固定屏柱与短导轨，装入旋钮总成；屏幕和线从固定柱通过，不跟随电机旋转。
4. 安装后部两块板和前部定制电池，接入排线/线束；电池软垫独立，不以硬塑料挤压电芯。
5. 放入三个回位弹簧并合上带定位座的底盖，最后安装光导、固定屏与握持圈。

这是设计顺序，尚未以实物证明完整工具可达性。电机定子固定面、转子到带轮的连接、轴与带轮的夹紧、轴承压环螺钉和导轨紧固孔仍需按实物/供应商图详细化。不能把现有空心轴包络或电机鞍座上的保留环直接当作最终夹紧结构加工。

## 单套机械件大概多少钱

采用 **打印外壳/底盖 + 金属承力件** 的混合工艺，去重后的基础工程预算约 **¥1,300–¥3,700/套**。主要花费在单件机加工，标准带、轴承本身占比不高。

| 费用 | 一套预算 | 说明 |
| --- | ---: | --- |
| 同步带、两轮、两轴承、导轨滑块、三弹簧、螺钉及零散五金 | ¥173–¥526 | 含小批量购买余量；精确型号、轮孔与张力尚需供方确认 |
| 打印件、金属旋钮/轴/三臂件/承力架、固定支撑、光导及按钮帽 | ¥1,080–¥3,160 | 工程估算，无正式加工报价；已去除重复旋钮及合并座的重复计费 |
| 基础合计 | ¥1,253–¥3,686 | 沟通时取整为 ¥1,300–¥3,700 |
| 首件试装与配合返工另留 | ¥300–¥800 | 不是必然支出，也没有混入电子 BOM |

以上不含电机、屏幕、电池、PCB、运费和税费。用户自行打印壳体可减少外包打印费，但不能等额扣掉金属承力架、轴和带轮的加工预算。没有用整套进口“零回差”带轮价格，也没有给国产低价件作同等性能保证。三颗 M1.6 灯板螺钉计入零散五金；弹簧的 Ø4.4/Ø3 是外包络和中心避让，不是已冻结的线径、圈数或弹簧率。

现价锚点与逐项区间见[取证预算表](../outputs/01a08963-e2d7-71e2-a353-8710a44dc948/r5-review/mechanical-cost-evidence.md)。例如标准 6901 的外形为 12×24×6 mm，但同尺寸不同品牌、密封和游隙的价格及摩擦均不同；不以最便宜 C3 型作为本机低游隙定选。[供应商规格及目录价格](https://www.caloc.cn/product/B01/03/001/6901.html)

## 已完成的验证范围

主脚本检查三处按压位置（0 / 0.175 / 0.35 mm）、主旋转件的连续 360° 扫掠、张紧范围两端的电机位置、灯窗与遮光结构、PCB/电池安装空间以及合并结构的有效单实体。STEP 另行重新导入验证实体数量和有效性。具体来源哈希和结果随模型附带。

当前主检查 **17 项通过**；独立审核在三处张紧设置与两端按压位置进行了 **2,910 条机械间隙检查，0 干涉失败、0 布尔计算错误**。两处螺纹配合和带齿/轮齿包络重叠单独记录，不计作间隙通过。交付 STEP 重新导入为 **171 个有效实体、95 个命名项目**；不把供应商器件模型的简化计为机械装配件数量下降。

尚无整机实物、反转迟滞、加载刚度、光学均匀性、按压寿命或电气/热测试。本轮没有改动固件出力参数。

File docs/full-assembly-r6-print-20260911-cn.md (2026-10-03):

# GL30 R6：内收侧键、抬高面板与打印试装

2026-09-11。外形底面积保持 **104 × 98 mm**，旋钮收腰外形和 **1∶1 短同步带**保持。本版调整外壳、按钮及光导的位置，并提供独立打印件用于无电试装。未进行实物打印或电机加载试验。

## 文件入口

- [完整装配 STEP](../output/models/GL30_FULL_R6/GL30_FULL_R6_ASSEMBLY.step)
- [外观图](../output/models/GL30_FULL_R6/exterior_r6.png) · [侧键与顶面字样](../output/models/GL30_FULL_R6/side_key_wordmark_r6.png)
- [内部布置](../output/models/GL30_FULL_R6/internal_layout_r6.png) · [灯圈真实剖面](../output/models/GL30_FULL_R6/light_ring_section_r6.png)
- [打印包说明与分件清单](../output/print/GL30_R6_PRINT_FIT/README_CN.md)
- [打印分件、整机 STEP 与预览图压缩包](../output/print/GL30_R6_打印测试与整机模型_20260911.zip)
- [装配几何记录](../output/models/GL30_FULL_R6/verification.json) · [打印文件与尺寸清单](../output/print/GL30_R6_PRINT_FIT/geometry_manifest.json)

## 外形改动

截图中后侧键帽跨入了外壳的后圆角。两侧各两个按钮的中心由 Y=24/39 mm 改为 **Y=7/23 mm**，向使用者方向移动 17/16 mm。按键外表面由 |X|=51.7 改为 **51.3 mm**，相对 |X|=52 mm 的直侧壁内陷 **0.7 mm**。按钮高度同时上移 2 mm，避开前移后靠近的电机空间。保留 0.2 mm 名义侧键行程，并修正旧键帽与顶杆之间的断开，使每只键帽成为可单独打印的连续实体。

独立装配检查发现，旧一体侧键座挡住键帽从内向外的直线装入。本版改为**左右各一条可拆双键支座**：空壳先放四个键帽，再装已放入开关的两条支座，用每侧两颗 M2×4 从底部向上锁紧，最后安装电机和电路板。壳体保留四个一体安装台，支座用 Ø2.4 通孔、安装台用 Ø1.7 导孔；螺钉及打印螺纹配合需按实样确认。相对 R5 增加两条可拆塑料件和四颗小螺钉，用来获得明确的装配顺序。

名义装入路径避开灯框：键帽先低 1 mm，向外移动至距终位 3 mm，再抬正并推出；双键支座先低 3 mm 横移到位，再抬起锁紧。右支座增加局部光框避让，顶杆入口向上开放。键帽的三个矩形特征分别构造逐段连续扫掠体，双键座按横移和抬升位置检查。安装台与支座只是面接触，任何正体积相交均视为干涉，没有借“装配接触”放过冲突。

旋钮背后的斜面沿旋钮轴向抬高 **2.3 mm**，相当于竖向抬高约 **2.559 mm**。后水平面由 Z=62 抬至 **67 mm**，折线移至约 **Y=20.61 mm**，使光导圈后沿完整落在斜面内。内顶面按两块外平面各内偏置 3 mm 后求交，保持主体屋顶名义厚度；光导孔、螺孔和刻字处分别形成局部特征。

光导仍是 Ø67.0 / Ø64.2 × 0.9 mm 的独立连续环，上表面移至轴向 N=2.3，与面板和内遮光罩上表面齐平。三处隐藏桥的支撑面随之抬至 N=1.4。外圈与壳体合并，减少多层外露台阶。内遮光罩 ID=56.8，旋钮裙边 OD=56，名义径向间隙仍为 **0.4 mm**，没有把运动间隙填死。

旋钮、屏幕和核心机构高度未移动，整机最高点仍由旋钮决定。屏幕继续由内部固定柱支撑，没有外置桥架。板上电子小封装继续隐藏，PCB 板框、接口、电池及承力件保留。

## 表面工艺与字样

采用深石墨灰外壳、细哑黑旋钮、浅灰小字和连续灯带。下面是本套样机的选定外观方向，渲染颜色不代表已制得的涂层样板。

| 部位 | 材料与处理 | 图文安排 |
| --- | --- | --- |
| 底座外壳、底盖 | 先用普通 PETG 打印试装；尺寸确认后再做外表面填纹、打磨及哑光石墨灰涂装 | 顶后左侧只保留 `GL30`，不刻操作说明或整圈数字 |
| 收腰旋钮 | 6061 铝加工，细玻璃珠喷砂后做黑色普通装饰阳极氧化；保留圆肩和细腻收腰 | 保留现模型小指示槽；精密配合面和紧固面另按制造图控制 |
| 四侧键 | 深灰，与壳体接近 | 按现有预览的映射：左后计时器、左前音量、右后 `+`、右前 `−`，使用小图标；本轮侧键图标为后处理方案，未刻入键帽 |
| 后电源键、USB-C | 黑/深灰 | 小电源符号和 USB 符号靠接口放置；不标未经实测确认的充电功率 |
| 光导 | 最终使用乳白扩散材料样件确认效果 | 连续细环；打印件只验尺寸，不作为均光性能样板 |
| 底部 | 保留便于后续补标的区域 | 版本和编号放底部，例如 `GL30 · R6 / 001`；实际电气额定值冻结后再补 |

顶面 `GL30` 已做入 CAD：中心 X=-28、Y=36 mm，Arial Bold，名义字号高度 3.4 mm，凹刻深 0.25 mm。STEP 中的浅灰填充体表示可选填色，打印外壳只包含凹槽，不把填色体作为塑料孤岛打印。单件外壳可直接用凹刻填灰，避免另做金属铭牌；若以后做阳极铝外壳，再单独选择阳极后激光标记。

玻璃珠喷砂、阳极氧化和零件标记均为现有加工服务；阳极后激光标记也有明确厂家工艺说明。这里选用这些工艺作为设计方向，没有将供应商服务宣传当作本件耐磨或外观验收。[Protolabs 工艺说明](https://www.protolabs.com/en-gb/services/post-processing/laser-engraving/)、[CNC 表面处理指南](https://www.protolabs.com/media/1022663/cnc-uk-surface-finish-guide.pdf)。

## 打印试装范围

打印包有 **13 种分件**，每种提供 STL、3MF、STEP；3MF 只有几何，没有打印配置或 G-code。每个件已转换到注明的打印方向并放到 Z=0，清单记录了源 STEP、体积、包络、变换和文件哈希。所有单位是 mm，100% 导入。

先打印 **01 外壳、02 底盖、03 承力支架**；08 收腰旋钮可单独检查握持感。09 同型侧键帽需要四只，12/13 为左右可拆双键支座，其他按需要各一只。外壳内顶面及侧孔需要检查支撑，底部保持开放便于去除。用户自行切片和选择实际材料配置。

PETG 常用于机械支架和夹具，但具体牌号、打印方向、孔收缩及层间性能仍需实样确认。[Prusa PETG 说明](https://help.prusa3d.com/article/petg_2059)。轴承孔按名义几何保留，不能以 CAD 的 Ø24 直接保证 FDM 压配；光导两侧各 0.1 mm 的名义间隙也需要实样配合。不得靠强压轴承或挤压电池完成试装。

承力架、滑座、导轨支架和固定屏柱在本包里是塑料尺寸样。电机定子固定接口、转子带轮连接、轴承保持与导轨紧固细节仍需实际型号尺寸，不把这些尺寸样作为最终金属架的刚度、带载或寿命证明。现有屏幕固定方案也不因打印网格通过而变成完整可上电样机。

## 验证与证据边界

主 CAD 检查覆盖 PCB/电池空间、三处按压位置、主旋转件连续 360° 扫掠、两端张紧位置、光导与遮光罩分离、侧键行程和合并件单实体。打印导出另检查正体积、单实体、摆放包络及源文件一致性。最终数值以随包的几何、网格和独立回读报告为准。

最终主检查 **20/20 通过**；独立网格和 CAD 回读检查由主线程重新执行，13 种分件、39 个格式文件全部通过，失败列表为空。STL/3MF 共 **26 个文件**在 Bambu Studio 02.08.02.61 离线导入中未报告修复。完整 STEP 回读为 **177 个有效实体**，102 个命名交付项目。主线程另从最终 STEP 检查已装入支座的四个开关，132 个装入姿态/障碍组合均无体积干涉。

最终 CAD 源 SHA256：`2a6dda65f4e350d9c1a55fe4118f1e59f3fc3ed1e04b69d4959a5ecabf86ac1a`。装配 STEP SHA256：`406fc66ecb6412c2288804b074d370c504b82d8e591486147ed758ad9c13f793`。模型图、打印 manifest、主线程独立复跑均绑定同一源。

独立分析提出的间隙与打印收缩问题保留为实样检查项。其中“两轴承孔中心距 13 小于孔径 24”不成立：两个轴承是**同轴、轴向分层**，13 mm 是轴向中心跨度。光导与内罩顶面共面也不自动意味着相交，两者径向分离，几何检查按实际实体执行。主线程没有采用这两条误判。

尚未完成真实打印、装配工具可达性、孔配合、按压晃动、表面触感、光学均匀度或电气/热验证。本轮没有改动固件出力参数，也没有进行打印机或电机操作。

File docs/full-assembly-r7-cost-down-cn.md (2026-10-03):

# GL30 R7：单套加工与打印优化

本版沿用 R6 的 104×98 mm 底面积、收腰旋钮、抬高后面板、四侧键和 1∶1 短同步带。针对一套样机，将难加工的一体结构改成浅平板、同轴车削件、短打印夹座及直管/隔柱；导轨定位面继续保持一体。没有改变固件出力或进行电机操作。

## 文件

- [整机 STEP](../output/models/GL30_FULL_R7/GL30_FULL_R7_ASSEMBLY.step)
- [新旧零件对照图](../output/models/GL30_FULL_R7/manufacturing_comparison_r7.png)
- [R7 打印包说明](../output/print/GL30_R7_COST_DOWN/README_CN.md)
- [完整试装包 ZIP](../output/print/GL30_R7_单套降本与打印模型_20260911.zip)
- [主几何检查](../output/models/GL30_FULL_R7/verification.json)

## 已做入几何的改动

| 部位 | R6 的制造难点 | R7 的结构和工艺 |
| --- | --- | --- |
| 承力架 | 底板、两层轴承座、细长连接筋合成约31.5 mm高的一件；深处刀具和打印支撑难接近 | 浅平底板最高4.5 mm；独立连续轴承筒用车削完成主要回转面，两端仅作轴向孔加工。轴承筒和底板用止口及三颗M3夹紧 |
| 轴承定位 | 两座之间有开窗和细筋 | 同一筒内贯通Ø24名义孔，底肩、7 mm外圈间隔环及0.6 mm薄压环保持两个6901的13 mm中心跨度。公差和轴承轴向预紧仍需实测选定 |
| 固定屏柱 | 长斜管和异形底脚融合，打印细孔不易清理 | Ø8/Ø6×57.1 mm直管配左右短夹座；直管可截取、去毛刺；夹座开合，管路可从侧面清理和装入 |
| 电路板支架 | 约27.2 mm高的悬空横桥连长腿 | 最高2.2 mm的开口平托盘，加两只25 mm直隔柱；PCB A/B安装平面仍为Z29.2/44 mm |
| 导轨支架 | 外背脊比底脚缩进2.5 mm，侧卧仍会悬空 | 背脊加厚至与原底脚外面X44.5齐平，保留一处浅侧开让位口以避开侧键；导轨定位面保持。绕世界Y+90侧卧后打印高度8.5 mm，局部孔/让位面仍检查支撑 |
| 外壳与小字 | 复杂壳体若整体按CNC报价不划算；3.4 mm小字的凹刻需要细工具 | 外壳仍优先打印；小号GL30改为后处理表面印字/转印，不刻入打印实体，不另做铭牌 |

这种拆分会增加标准紧固件和装配步骤，但减少高难度一体毛坯及深处加工。两个轴承仍由一个连续筒定位，导轨基准没有拆成多块拼接。不能把零件种类增加或减少直接换算为加工费变化。

制造商的设计指南将深腔、细长特征、多次装夹和小字凹刻列为成本因素，并建议在适当情况下拆成简单零件后紧固装配。本版按这些因素修改实际几何；这不是本项目的供应商报价。[Protolabs CNC降本说明](https://www.protolabs.com/en-gb/resources/design-tips/how-to-reduce-cnc-machining-costs/)、[Protolabs Network工艺建议](https://www.hubs.com/knowledge-base/reducing-cnc-machining-costs-design-tips/)。

## 这一套的加工分工

1. **自行打印**：外壳、底盖、PCB托盘、屏柱夹座、侧键座和键帽。先用现有材料配置检查尺寸，合适后再考虑外观涂装。导轨架可先打印试装。
2. **简单车削/平板加工询价**：连续轴承筒、外圈间隔环、浅平承力板。承力板仍有1 mm编码器避让和1.5 mm局部导轨垫高，均是浅面特征。筒上螺孔由轴向钻攻完成；不能按“纯车一刀成形”报价。
3. **购买或截料**：8×6直管、25 mm M2隔柱、螺钉与螺母。网格里也给了直管/隔柱尺寸样，方便试装，不要求将金属标准件改为塑料长期使用。
4. **保留单独评估**：旋钮、输出轴、带轮与电机滑座。收腰外轮廓没有改成直筒。低矮36T带轮的成品适配、定子固定和转子连接仍需实际供应商尺寸，不应将占位轮齿和电机安装包络当作可直接下单的制造图。
5. **薄片件**：0.6 mm压环可由合适板材切割；打印件只验证孔位和空间。弹片的材料、固定根部和力—位移关系需样件确定。

先按分件和工艺分别询价。不要让加工方把整机STEP中的PCB、电池、光学件、螺钉包络及所有塑料件一起按铝件铣削报价。当前未取得加工商正式报价，因此不承诺节省金额或百分比，也不把R5的粗预算当作R7成交价。

## 新接口与装配

- 轴承筒底止口Ø18×1.2，对应底板Ø18.2孔；三处M3安装轴在局部(12,0)、(-12,0)、(0,-12) mm。孔位呈非共线三角形，避开固定屏柱夹座和后弹簧座。端面负责夹紧，止口负责中心定位；名义间隙不是金属最终配合公差，也不能保证FDM直接插合。
- 轴承筒用三颗M3×8；顶部压环用两颗M2×4。螺纹在CAD中使用导孔和螺钉包络表达，没有生成螺旋牙型。装配验证把这几处有意的螺纹啮合单独列出，不把其他实体重叠算作通过。
- 屏柱先放进两夹座，用M3×25与M3螺母横向夹紧，再以两颗M2×5从底盖固定。夹座名义孔Ø8.2，两半各向中心闭合0.1 mm；应按实物管径与打印收缩确认夹紧量。保留屏柱与旋转轴的径向间隙，夹紧不能把直管挤弯。
- 两只25 mm板柱用两颗M2×6从底盖固定。后部两颗M2×25穿过板堆后锁入隔柱，前部两颗M2×20配两只M2螺母固定。板堆原有13.6 mm间隔件的公差仍需匹配。
- 保留R6侧键装配次序：空壳先放键帽，再装双键座和开关，随后装内部机械和板件。新增底盖固定件均从外侧操作。

新增紧固件纳入检查时，发现原模型几处未详细处理的空间重叠，已随本版修正：托盘前横梁改为开口并收窄右边；屏柱底脚避让弹簧座；左后脚垫移动以让开板柱螺钉；内部制动模块的等体积空间预留前移2 mm。B板三个元件包络为避开固定螺钉微调了位置，未改变器件型号或BOM；这些板目前仍是未布线的机械占位。

按压弹片缩短前端并增加板柱避让口，仍是单片平面形状。其有效弹性发生变化，必须重新确定弹片固定和按压力，不能宣称按压手感已保持原值。旋转传动比、导轨定位面、轴承跨度、0.35 mm名义行程以及旋钮/屏幕位置保持。

## 打印与证据边界

打印件均以mm、100%导入，3MF仅含几何。建议先试承力板、轴承筒、左右屏柱夹座与PCB托盘；先查关键孔和止口配合，再打印整壳。不要强压轴承。19种分件中，侧键帽四只、PCB直隔柱两只，其余按需要各一只。切片和材料配置由用户自行选择，不提供G-code，也未连接打印机。

本包支持无电尺寸、布置和装配检查。轴承座配合、连接预紧、导轨紧固细节、电机接口、手感/刚度、回差、散热和寿命均没有实物验证。轴承筒等金属件的塑料尺寸样，不是带载替代件。

## 本次交付验证

- 主CAD的23项检查全部通过。新增拆分接口检查4,712组实体对，没有未解释的体积干涉；13组有意的螺纹啮合单独记录。检查范围包括按压位置、旋转扫掠、张紧调整、侧键装入和电池/板件空间，不代表结构强度验收。
- 独立检查及主线程复跑均通过：19种模型、57个格式文件；STL/3MF为闭合单连通网格，逐件STEP回读有效，体积/包络与导出记录相符。整机STEP回读为197个有效实体，与导出清单一致。
- Bambu Studio离线导入38个STL/3MF文件，均未报告网格修复。没有切片、生成G-code或联系打印机。
- 导轨最终侧卧包络56.49×26.85×8.50 mm。独立平面筛查仍有约127.59 mm²下悬候选面，距床约2.5 mm；这是侧键让位口，需在切片时确认局部支撑。该筛查不是免支撑或实际支撑用量证明。
- CAD、分件、整机STEP和预览均核对了同一份最终源文件SHA-256。包内保留几何、网格/STEP和导入报告，以及文件校验清单。

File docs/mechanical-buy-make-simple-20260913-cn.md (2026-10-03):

# 现在要买什么、加工什么

按2026-09-14更新：电机和3D打印件已有，多项机械标准件及定制薄板已下单，尚未完成实物尺寸和装配核验。本清单只覆盖机械装配试验；最新订单差异见[订单核对记录](../outputs/r11-jlc-manufacturing/purchase-order-audit-20260914/订单核对记录.md)。

螺钉头部尺寸已按你反馈的现货更新；改模与局部替换件见[现货螺钉适配](standard-fastener-fit-20260913-cn.md)。

[打印与加工模型合集](../outputs/r10-standard-fasteners/GL30_打印与加工模型合集_20260913.zip)中的打印件继续沿用：03/07/21/31各1件，08支架可修旧件；本次没有新增补打改动。加工件已更新到[R11嘉立创参数与模型包](../outputs/r11-jlc-manufacturing/GL30_嘉立创加工参数与模型_R11_20260913.zip)，以R11的金属接触面、螺纹和配作要求为准。

## 买成品

- 闭口同步带：156-2GT-6，1条。
- 同步带轮：36齿、2GT、配6mm带宽，2只。A形薄款、总宽10.3mm；10mm孔、12mm孔各1只。先核卖家图再买；没有同尺寸12孔成品时，让卖家给标准轮扩孔，不能把普通16/18mm厚轮直接代入。
- 轴承：6901ZZ，12×24×6mm，2只。
- 直线导轨：MGN7轨道35mm＋MGN7C短滑块，1套。让卖家切35mm并保证轨道两孔中心距端面10/25mm；轨和块同家配套。
- 回位弹簧：外径4.5、线径0.35、自由长8mm，买6只（装3只、备3只）。先用于试按压力。
- 固定屏管：304不锈钢管，外径8、内径6、长58.7mm，1根；让卖家切好，试装先不加工上端螺纹。
- 轻触开关：SKRPASE010，买10只（装6只）。
- 脚垫：直径8、厚1.2mm，买6粒（装4粒）。
- 紧固件：按下面的小清单备齐。

## 找人加工

[下载R11嘉立创参数与模型包](../outputs/r11-jlc-manufacturing/GL30_嘉立创加工参数与模型_R11_20260913.zip)：11种13件，每个分件STEP做1件，含材料、螺纹、表面处理及薄板DXF。两只带轮、两只6901ZZ已下单；轴承轴孔、隔套和调整垫等仍需等实物到货后按图配作，采购状态不代表配合尺寸已冻结。

- 电机转接毂：1件。
- 中空输出轴：1件。
- 双轴承座筒：1件。
- 输出轴薄锁母：M12×0.75，1件。
- 轴承内外隔套、上部调整垫：1套（内隔套1、外隔套1、调整垫一组）。先问有无对应精密成品，没有再与轴系一起配做。
- 薄板件：轴承压盖1件、导轨背板1件、按压弹片1件；集中切板、钻孔和去毛刺。R11已含4.3孔距弹片和修订压盖；薄板DXF与STEP是同一件，不重复计数。
- 按压硬止挡：3件，简单切料并按实物行程修端面；标准可调止挡替代方案尚未落实，不把它当成已可直接替换的采购项。

带轮和轴系先核尺寸、询价；R11为询价与配作图，配合尺寸要等标准件到货后落实。若买不到合适的12孔轮，仅增加该轮扩孔工序，不自制同步齿。内部金属件统一本色去毛刺、清洗，指定配合面按图精加工。

外壳继续使用已有打印件。屏幕、电池、灯板、PCB柱/隔管、最终塑料壳在对应装配阶段再安排。标准轮新排布涉及的03按压底板、07电机滑座、21三臂连接架，以及螺钉适配后的31连接架，现已按候选总装导出为无电装配打印样，放在上方合集；不要求整套重打，也不代表实物配合或长期承载已通过。

## 紧固件小清单

以下为采购小包装数量，包含少量备用。薄头要求不能用普通高杯头替代；M2、M3沉头和非沉头分开买。

- M2×4薄头机牙：20颗；头径4、头高0.8mm。
- M2×5薄头机牙：10颗；头径4、头高0.8mm。
- M2×6薄头机牙：10颗；头径4、头高0.8mm；导轨沉孔按卖家实际图核对，当前参考为Ø4.2深2.3。
- M2×6、90°沉头机牙：10颗，用于底盖。
- M2.5×5低头机牙：4颗；头径≤4.5、头高1.8mm。
- M3×8薄头机牙：买5颗、装3颗；轴承座底部改用头径6、头高1mm，每颗配两片0.5mm平垫。原2mm高头加垫后会碰底盖。
- M3×8、90°沉头机牙：5颗，用于导轨底脚。
- M3×25低头机牙：2颗；头径≤5.5、头高≤2.0mm。
- M3×10平端止付螺钉：2颗，无头内六角，DIN913类。
- M2×3低头机牙：5颗；头径4、头高1.4mm；新弹片与31连接架配对采用4.3mm孔距。
- M3平垫：内径3.2、外径6、厚0.5mm，买10片；R11装9片，含电机3片和轴承座底部6片。
- M3六角螺母：5颗，标准粗牙。
- M2热熔铜嵌件：内牙M2、外径3.5、长4mm，10颗。
- 电机固定螺钉：定子M3×5买5颗、转子M3×3买6颗；均选头径6、头高1mm的薄头款。头径5.3、头高2mm款不用于这两处。定子保留0.5mm平垫；先核电机实际牙深，合适的原厂附送件优先使用。
- 电机轮固定顶丝：优先使用带轮随附的2颗。引用目录对应M4×3；国产轮以卖家配套规格为准，不另按未经核对的长度买。

PCB与灯板还没有实物时，M2×20、M2×25、M1.6×4、M2螺母及板柱先不买；真实屏幕的3颗M2×5也后买。

依据：[当前标准轮候选与18种零件处理](standard-parts-first-20260913-cn.md)、原R8紧固件清单；[标准带轮目录](https://www.misumi.com.cn/pdf/fa/2013/p825.pdf)、[开关原厂规格](https://tech.alpsalpine.com/c/products/detail/SKRPASE010/)。

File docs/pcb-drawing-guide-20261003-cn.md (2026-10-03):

# GL30 电路板绘制指南：先完成 A 板布局

更新：2026-10-03。软件选用 **Altium Designer**，继续使用你已经补入的封装库，不重新选芯片，不增加测试点。当前约定是：**原理图复核 → 器件布局 → 布局审查；这一步先不布线、不投板。**

## 1. 先打开哪个工程

本机入口：

`G:\Agent\GL30-Haptic-Control\hardware\pcb\stm32-foc-a-altium-r6\GL30_A_STM32_FOC_NO_TP.PrjPcb`

你已有原理图，不需要从空白重新画。这个 R6 工程有七页、146 个位号，测试点已删除；本机完整库环境下，142 个位号已有封装关联。9/27 留存的 AD 记录为 **0 错误、34 警告**：4 个自定义焊盘缺封装、30 个无驱动源提示，仍需逐条复核。现在没有 `.PcbDoc`，也没有布局、走线或 PCB DRC 通过记录。

GitHub 中的 R6 是**原理图公开快照**：七页原生文件、BOM 和原验证记录可读；个人库及其派生库不重新分发。公开副本的工程文档列表移除了五份未分发库，但符号中的封装名称、库名称和针脚映射保留。本机完整工程保持原样；在本机继续画板用上面的原工程。公开包中的历史验证不代表缺少个人库的下载者可以直接复现封装检查。

| 板 | 要画的内容 | 目前可以推进的工作 |
| --- | --- | --- |
| **A：控制/FOC 板** | STM32G474CET6、DRV8316R、电流与母线采样、编码器、NTC、硬件保护、板间接口 | 原理图复核、补四个焊盘封装、机械匹配、器件布局 |
| **B：电源板** | USB-C/PD、3S 充电及供电路径、母线隔离、INA228、制动 | 先完成原理图和 A/B 接口核对，再布局 |
| **C：灯环/按压板** | RGB 灯、按压与按钮、环境光、显示模组转接 | 先完成原理图和接点方向核对，再布局 |

Waveshare ESP32-S3 AMOLED 屏幕板和电机原厂 AS5048A 小板沿用现有模块。不要把它们再画成第四、第五块自制板。

## 2. AD 中实际怎么操作

1. 打开 R6 `.PrjPcb`，核对 `Project Options` 的网络作用域为 **Global**。七页跨页同名标签按这个作用域连接，不要改为依赖层次端口。
2. 按 A01～A07 复核，运行工程验证。对 34 条警告逐条记录处理结果；不要用批量 No ERC 把它们隐藏。C53/C54 为可选 DNP 元件，预留位置仍需检查。
3. 在项目中增加 `GL30_A_STM32_FOC.PcbDoc` 并保存。先准备下表四个自定义焊盘封装，并确认其余封装在本机可解析。
4. 在原理图编辑器选择 `Design → Update PCB Document`。在 ECO 中先 `Validate Changes`，检查每条失败项；修正缺封装或针脚不匹配后，再 `Execute Changes`。导入后逐个核对位号、焊盘编号和网络，DNP 直焊接口不能因为“不买连接器”而从 PCB 删除。
5. 用当前机械装配导出的板框和孔位建板形，设置层叠和高度禁区。先放安装孔和接口，再按下一节放器件。界面可在 `Design → Layer Stack Manager` 设置层叠；DXF 导入机械层后，只选闭合板边轮廓，再 `Design → Board Shape → Define from Selected Objects`。
6. 保存布局，导出顶视图、底视图、带外壳的 3D 装配视图和尺寸表。检查零件及线束装配后，再进入后续布线。当前保留飞线；布线未完成，所以不应把未连接网络的 DRC 当作投板放行。

上述 ECO 和板框操作对照了 [Altium 原理图到 PCB 同步说明](https://www.altium.com/documentation/altium-designer/sch-pcb)、[板框定义](https://www.altium.com/documentation/altium-designer/pcb/defining-board-shape)及[层叠管理](https://www.altium.com/documentation/altium-designer/pcb/defining-layer-stack)。

### 布局前要补的四个封装

| 位号 | 功能与焊盘编号 | 怎么定尺寸 |
| --- | --- | --- |
| J1 | 母线直焊：1 MOTOR_BUS、2 GND | 按实物电源线外径、导体直径及剥线方式定孔径/焊盘，旁边留线束应力释放空间 |
| J2 | 三相直焊：1 MOTOR_U、2 MOTOR_V、3 MOTOR_W | 按电机实际线材定孔径、间距；相序标定还没有实板验收 |
| J3 | 编码器直焊：1 GND、2 5V_ENC、3 MISO、4 MOSI、5 SCK、6 CS_N | 按六根实线定焊盘；这是 A 板编号，不能直接推定厂家插头的物理顺序 |
| JP1 | 两焊盘焊桥：1 BOOT0、2 3V3；默认断开 | 做可以人工短接、正常使用保持断开的焊桥，不增加采购连接器 |

这四项都是板上几何，不需要另买四个端子。没有实线尺寸时不能把孔径随意冻结；可先摆候选位置，但需要在布线前确认。

## 3. 板框和层叠怎么定

**先适配已经打印并加工回来的结构。** 测量安装柱坐标、螺丝头占位、板上下净高、线束出口和装配入口，把这些作为机械层/禁止布件区；同步带、轮、浮动按压件的整个运动包络也要避开。FFC 要能插拔，不能只保证插座本体不碰外壳。

`hardware/cad/pcb_packaging.py` 中的旧草案是 **PCB_1P2_20260910**：A/B 为 98×34 mm、1.2 mm 厚、四层；C 为外径 74/内径 56 mm 的带耳环形板、1.2 mm 厚、两层。**这些尺寸只是旧包络线索。** R21 仍标为名义几何、实物配合待核，尚未包含新的 PCB；不能直接把 9/10 板框当作本次最终加工尺寸。

A 板先按四层规划，适合这个功率、采样和 MCU 混合布局。层叠建议是本项目的布局起点，最终厚度、铜厚和介质由实际空间及板厂层叠一起确认：

| 层 | 放什么 |
| --- | --- |
| L1 顶层 | 主要器件、DRV 近端功率回路、极短去耦连接、必要信号 |
| L2 内层 | 控制/采样区域连续的 GND 参考，避免信号跨参考地缺口 |
| L3 内层 | 分区电源铜及必要信号；相线开关区域避免向安静模拟区扩展 |
| L4 底层 | 低速接口、允许放在底面的低矮器件、地铜；不得侵入支架接触面 |

不要为了省面积把晶振、模拟采样和开关节点上下叠在同一位置。A 板是 MCU 和 FOC 同板，不要再拆出一块 MCU 板。

## 4. 器件按什么顺序摆

下面是**功能分区示意**，没有指定实际左/右朝向，也不是已完成的 PCB：

```text
母线入口 J1 ── 大电容/近端去耦 ── DRV8316 U2 ── 三相出口 J2
                                      │
                      SOA/SOB/SOC → 隔离/滤波 → MCU ADC
                                      │
                     硬件比较器 → HARD_FAULT_N → BKIN

编码器 J3 ── 接口保护/串联电阻 ── STM32 U1 ── 板间 FFC J5/J6
                                  │
                         24 MHz 晶振、复位、SWD J4
```

1. **安装孔、线束出口和 J5/J6。** 它们决定能否装进去以及排线能否接好，先固定。
2. **J1/J2 和 U2 功率区。** DRV 靠近母线入口与三相出口，给 VM/GND/三相及散热铜留足空间。先紧贴相应引脚摆去耦，再摆大电容；不要最后在空位里塞去耦。
3. **电流信号及硬件保护。** SOA/SOB/SOC 的前级隔离靠近来源，末端 RC 靠近相应 MCU ADC 脚。比较器、默认上拉/下拉及 BKIN 路径留出短而清晰的通路，不能穿过相线和 Buck 开关区域。
4. **STM32、3V3/3V3A 和晶振。** U1 是 **STM32G474CET6，LQFP48、7×7 mm 本体、0.5 mm 脚距**，不要换成 UFQFPN48 或 NUCLEO 的 RET6。供电去耦靠近对应供电脚，24 MHz 晶振靠近 PF0/PF1；晶振下面及附近不放相线/Buck 开关连接。封装依据见 [ST 数据手册](https://www.st.com/resource/en/datasheet/stm32g474ce.pdf)。
5. **编码器、SWD、复位与剩余元件。** 调试插头在装机后仍要插得上；检查 M2/M3 螺丝头、FFC 翻盖、插线和烙铁空间，不能只看器件的外框。

## 5. 以后布线时重点看什么

本节是布局时需要预留的连接路径，**本轮不执行布线**。

- **DRV 功率环路和散热。** VM 旁路和母线大电容的回路尽量短；CPH/CPL、CP、AVDD、VREF 的小电容紧贴对应脚。三相使用有足够截面的铜，跨层电流通道不能只靠单个小过孔。U2 底部 EP 要按对应 GND 网络焊接，并为地铜、散热过孔和钢网开口设计留空间。不要把 EP 当悬空机械焊盘。这些原则来自 [TI DRV8316 数据手册第 11 节](https://www.ti.com/lit/ds/symlink/drv8316.pdf)。
- **回流路径。** R6 当前采用同一个 GND 网络。按功率回流和安静模拟回流安排位置与铜形，结合 TI 的 PGND/AGND 布局示例复核连接；不能擅自改成两个不连接的地，也不要在 MCU/ADC/SPI 的参考地下面随意开缝。
- **模拟与保护。** 电流、母线、NTC 采样远离三相和 `BUCK_SW`；ADC 末端滤波回地就近，BKIN 硬件故障链要能直接工作，不依赖 ESP32 或软件停机指令。
- **UART/SPI/FFC。** 沿短路径安排参考地，避免跨相线、母线铜和分割区。FFC 每根线按脚号复核，不能凭“同面/异面”商品名称认定方向正确。
- **线宽与间距。** 普通信号、模拟、母线、三相和故障网分别建 Net Class。母线/相线按确定的铜厚、允许温升、连续/峰值电流、路径长度和并联过孔计算，制造下限再按选定板厂工艺校验；目前不能给一个通用线宽作为出力能力保证。

## 6. 与当前固件对应的关键脚位

以下是**产品 CET6**接口，不是 NUCLEO 台架针脚；精确网络连接以 R6 原理图为准。

| 功能 | STM32 管脚 | 对应硬件 |
| --- | --- | --- |
| 三路高侧 PWM | PA8/30、PA9/31、PA10/32 | TIM1 CH1/2/3 → DRV INHA/B/C |
| 三路低侧 PWM | PB13/27、PB14/28、PB15/29 | TIM1 CH1N/2N/3N → DRV INLA/B/C |
| 电流采样 | PA0/8、PA1/9、PB0/16 | SOA/SOB/SOC 隔离及 RC 后进入 ADC |
| 母线/温度采样 | PB1/17、PB2/18 | ADC 母线倍率 11；NTC 10k/B3950 |
| 硬件关断 | PB12/26 | `HARD_FAULT_N`，TIM1 BKIN，低有效 |
| 关桥控制 | PA3/11 | 开漏 `DRV_DRVOFF`；上拉/释放关桥，拉低允许 |
| 驱动休眠 | PA12/34 | `DRV_NSLEEP`，上电默认低 |
| 电机母线请求 | PB9/46 | `MOTOR_PWR_EN`，上电默认关闭 |
| 强制制动 | PA2/10 | `BRAKE_FORCE` → B 板，只要求开启制动 |
| 驱动 SPI3 | PB3/40、PB4/41、PB5/42、PB6/43 | SCK/MISO/MOSI/CS，当前固件 5 MHz |
| 编码器 SPI1 | PA5/13、PA6/14、PA7/15、PA4/12 | SCK/MISO/MOSI/CS，当前固件 Mode 1、16 位、2.5 MHz |
| 与 ESP32 通信 | PB10/22 TX、PB11/25 RX | 经电源域缓冲交叉到 ESP GPIO44 RX、GPIO43 TX；5 Mbps、8N1 |
| 板间 I²C | PA15/39、PB7/44 | SCL、SDA；当前固件 400 kHz |
| SWD | PA13/37、PA14/38、NRST/7 | J4 的 SWDIO、SWCLK、NRST |
| 不引出 | PC14/3、PC15/4、PA11/33 | **R6 明确 NC，无测试焊盘；ADC 使用内部 TIM1 TRGO2/OC4 触发** |

旧 `board_config.h` 的描述表仍把 PA11 标为 AF11/CH4，部分历史接线文档也仍保留测试焊盘描述。这里区分内部定时器功能与 R6 外部连接：**不要因此在板上恢复 PA11、PC14、PC15 的测试点或触发走线。** 该描述表的同步核定属于后续代码维护，本次没有改动冻结固件源码。

### J4：单排 5P、2.54 mm 调试口

| 脚 | 1 | 2 | 3 | 4 | 5 |
| --- | --- | --- | --- | --- | --- |
| 信号 | 3V3/VTREF | SWDIO | GND | SWCLK | NRST |

一脚方焊盘。VTREF 是目标板电压检测，不接 ST-LINK 的 5V 或电源输出。沿用本机 R6 派生封装：完成孔径 1.02 mm、焊盘 1.70 mm。这个排列是本项目单排接口，不能按旧版 2×5 Cortex 插座的位置连接。

### J5/J6：均为 FH12-10S-0.5SH(55)，10P、0.5 mm

R6 库已核对 10 个信号焊盘及两片固定焊盘；固定焊盘 11/12 不是额外信号。下面是 A 板原理图脚号，不代表 FFC 到另一端必然同号。

| 脚号 | J5：A↔B | J6：A↔C/ESP 转接 |
| --- | --- | --- |
| 1 | 5V_LOGIC | GND |
| 2 | GND | ESP_UART_RX |
| 3 | I2C_SCL | ESP_UART_TX |
| 4 | I2C_SDA | GND |
| 5 | GND | SYS_FAULT_N_ESP |
| 6 | BRAKE_FORCE | I2C_SCL |
| 7 | HARD_FAULT_N | I2C_SDA |
| 8 | MOTOR_PWR_EN | 3V3_AUX |
| 9 | 3V3_AUX | 3V3_ESP |
| 10 | GND | GND |

A 板自己的 `3V3/3V3_AUX` 与 `3V3_ESP` 是不同电源域，不因为同为 3.3V 就并联稳压器输出。显示模组的 12P 接口经 C 板转接，不能直接插 A 板的 10P 接口。接触面、针一方向、实际排线连续性及原厂编码器小板去耦仍需按实物核对。

## 7. 布局完成后交什么

- `.PrjPcb`、七页 `.SchDoc`、新建的 `.PcbDoc` 和项目内新增四个自定义封装；本机继续引用已确认的个人库。
- 更新后的 BOM、针脚/网络/焊盘匹配记录，34 条警告的逐项复核表。
- 板框、孔坐标、板厚、上下限高、线束与按压/皮带运动禁区的尺寸说明。
- 顶视/底视布局及真实结构装配视图，未布线网络仍清楚可见。

当前软件的 `GL30_ELECTRICAL_ZERO_VALID=0`。固件构建和离线回归通过没有替代自制板的供电、硬件关断、相序、电角零位、热和实际手感验证；这份指南也不是 Gerber 或可直接投产的板件。

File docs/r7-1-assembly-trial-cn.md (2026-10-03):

# GL30 R7.1：导轨补实与装配试验准备

## 导轨中间为什么有缺口

斜脊和底脚交界处原来留有V形缺口，背面仍连为一个实体，但这处缺口没有必要保留。R7.1把底脚高度由22提高到26 mm，上表面从世界Z24提高到Z28，补实交界处。只增加约127.97 mm³材料，外包络和8.5 mm侧卧打印高度保持。

上方靠侧键的浅槽承担另一项作用：给右侧双键座和外壳安装台让位。试算直接封平这处浅槽，会与按键座重叠约76.19 mm³、外壳安装台重叠15 mm³。因此保留这处让位，不能把两处缺口一起封掉。

- [导轨修改对照图](../outputs/01a08963-e2d7-71e2-a353-8710a44dc948/assembly-trial/guide_change_r7_1.png)
- [R7.1模型包](../output/print/GL30_R7.1_导轨闭合与装配试验模型_20260911.zip)
- [购买、加工、打印单sheet清单](../outputs/01a08963-e2d7-71e2-a353-8710a44dc948/assembly-trial/GL30_R7.1_装配试验购买加工打印清单.xlsx)

## 先做哪种试验

本次先做无电空间、孔位和部件配合检查。以前的19种模型是尺寸样，不是已补齐所有连接的完整运动机构。本次额外导出11种原整机已有的几何：输出轴、三臂架、屏幕托盘、后开关座、板间隔管、止挡、内圈隔垫、A/B/C假板及电池占位块。总计30种模型，每种均有STL、3MF、STEP。塑料尺寸样不证明其能替代金属承力件。

无需先购买电池、焊接控制板或加工整套金属外壳。电池位置可用纸板/泡沫块，板件用假板；电机与屏幕已有实物时用于核对，尚无实物时暂不为外壳试放重复投入。

## 现在可以准备

| 物件 | 装机量／准备量 | 本次用途 |
| --- | --- | --- |
| 6901轴承，12×24×6 mm | 2／2只 | 检查轴承筒空间和接口，不强压打印孔 |
| 外Ø8、内Ø6直管 | 1段100 mm短料，截成57.1 mm | 试固定屏柱与左右夹座 |
| M2双内牙、25 mm长隔柱，外Ø5 | 2／2只 | 试装PCB托盘与假板 |
| SKRPASE010开关，4.2×3.2×2.5 mm | 7／10只 | 四侧键、后电源、复位、旋钮按压；含3只备料 |
| M3/M2螺母、低头小螺钉 | 逐项数量见单sheet | 螺钉直径、长度和头型同时核对；不能只看“M2” |
| Ø8×1.2硅胶脚垫 | 4／6只 | 桌面摆放；检查螺钉头是否低于脚垫 |
| 薄绝缘软垫、卡尺与精密批头 | 已有材料/工具优先 | 配合测量和无电试装 |

6901标准尺寸核对自[NSK产品数据](https://www.nsk.com/jp-ja/engineering/products/bearings/ball-bearings/deep-groove-ball-bearings/6901-apn.html)，开关尺寸核对自[ALPS产品资料](https://tech.alpsalpine.com/c/products/category/tact-switch/map/)。品牌、密封型式和供方报价尚未定选，不要求购买进口品牌。

## 哪些打印，哪些加工

| 路线 | 零件 | 安排 |
| --- | --- | --- |
| 直接3D打印试装 | 外壳、底盖、导轨支架、左右屏柱夹座、PCB托盘、侧键座及键帽、后开关座 | 先检查局部接口，再打印整壳；尚缺固定接口处不能仅凭摆放认为已装牢 |
| 先打印尺寸样，再决定金属加工 | 承力板、轴承筒、输出轴、三臂架、屏幕托盘、电机滑座 | 最终公差/固定方式补齐后再下加工单 |
| 简单车削/平板加工 | 轴承筒、输出轴、承力板、外圈间隔环 | 功能依赖配合和端面精度，不用普通FDM孔替代轴承精密配合 |
| 截料或薄片加工 | 屏柱直管、13.6 mm板间隔管、0.6 mm压环、0.7 mm内圈隔垫、止挡 | 管材和小薄片不必按复杂整块CNC报价；厚度与端面仍须匹配 |
| 可选外观件加工 | 收腰旋钮 | 本次先打印。确认尺寸、连接与握持后再考虑铝件与表面处理 |
| 先选成品并匹配接口 | MGN7C导轨滑块、同步带及36T带轮 | 导轨和同步带不用打印；带轮齿形/轮毂不能按当前光滑包络加工 |

## 完整手动运动装配前，还缺的真实接口

1. **导轨固定**：当前轨长35 mm，导轨与滑块、支架底部的孔距、数量和紧固件尚未完整表达。HIWIN MGNR7标准长度表从40 mm起；35 mm应向实际供应商确认裁切、孔位和端距。国产同尺寸件也须按供方图核对，不是随意购买50/100 mm后直接装入。[HIWIN轨长规则与尺寸表](https://www.hiwin.com/wp-content/uploads/Linear_Guideway-E-2.pdf)
2. **底盖紧固**：原包络是Ø2螺杆、长5.5 mm，壳体孔却为Ø2.2 mm，不能形成有效螺纹啮合。这次已明确标为待修正项，没有把这4颗包络写成可以直接买的“M2×5.5”。
3. **传动及轴向限位**：电机定子固定、转子接头、轮毂夹紧、输出轴与三臂架/旋钮的固定、挡圈槽和轴承预紧尚需补齐。普通标准36T轮未必满足当前Ø27、7.6 mm高的低矮空间。
4. **屏幕与按压链**：管端到托盘的抗扭固定、屏幕螺钉、后开关座固定、止挡固定、三弹簧的完整规格及按压弹片根部和力—位移关系仍缺。弹簧外Ø4.4、内避让Ø3、装高5.5 mm只是安装空间，不是可采购的完整弹簧型号。

因此，当前可以开始打印和部件配合试验；完整的“装牢后顺畅旋转、按压自动回位”试验还需要补齐上述接口。加工单中的待确认项不能用任意孔、公差或螺钉替代。

## 本次文件验证

- 与R7逐零件比较，仅导轨支架几何发生变化；补料约127.97 mm³，没有删减实体。
- R7.1全量23项几何检查通过，整机STEP回读为197个有效实体。检查没有覆盖紧固件能否真实锁紧、摩擦、强度或手感。
- 原19种分件和补充11种分件，均完成闭合网格、单连通性、STEP回读、体积及包络核对。
- 60个STL/3MF文件均通过Bambu离线导入，未报告网格修复。未切片、生成G-code或连接打印机。
- 清单为单sheet，数量区分装机需求、本次准备量和暂缓项。当前没有正式加工报价或实物装配结果。

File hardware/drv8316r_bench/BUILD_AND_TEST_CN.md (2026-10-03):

# GL30 DRV8316R 验证子板：制作、焊接与测试

## 1. 下单前

- PCB：4 层、1.6 mm、外层 1 oz 起步、阻焊绿色、建议沉金；尺寸按实际布局，目标约 70×55 mm。
- U1 必须让 SMT 厂贴，或用钢网+回流台；不要用烙铁拖焊中心裸露焊盘冒充合格贴装。
- 外周 TH 端子和测试环可手焊。装配图必须标出 J_PWR 正负、电机 A/B/C、U1 1 脚、D1/TVS 极性。
- DRV8316R、TLV1704、电容的耐压和温度等级按 BOM 核对；DRV8316T 不可代换。F1 必须是有明确 I²t 的 3 A 延时型，首次上电仍用限流电源缓升。
- 让 PCB 厂对 U1 热过孔做底面盖油/填孔能力确认；不确认就先让贴片厂评估吸锡风险。

需要的台架：可限流电源、万用表、至少 100 MHz 示波器、10×探头短地弹簧、逻辑分析仪、可调 0–3.3 V 注入源、三个同批次 `10 Ω/50 W` 低感电阻和散热板。首次测试不接电机。

## 2. 焊后不开电检查

1. 显微镜检查 U1 四边、中心焊盘回流痕迹、D1/TVS、电解电容极性和 1 脚。
2. 万用表电阻档检查 `VM_RAW-GND`、`VM-GND`、`3V3_CTRL-GND`、OUTA/B/C 对地；电容充电导致读数变化正常，稳定近 0 Ω 不正常。
3. 二极管档确认 D1 只允许 VM_RAW 向 VM 正向导通。
4. 检查 HARD_FAULT_N 对 3V3_CTRL 是 2.2 kΩ 量级；DRVOFF 对 3V3_CTRL 是 10 kΩ；六 PWM 对 GND 各是 100 kΩ 量级。
5. 检查 SW_BK 到 FB_BK 为 22 Ω；FB_BK 到 GND_BK 能看到 22 µF 充电行为。

任一近短路、方向不明或 QFN 桥连，停止上电。

## 3. 只上 3V3_CTRL

VM 保持断开，电源给 `3V3_CTRL=3.3 V`，限流 20 mA：

- DRVOFF 必须高于 `2.7 V`；10 kΩ 外部上拉与芯片内部下拉会使它略低于 3.3 V，但仍应明显高于官方 `VIH=1.5 V`。
- CS_N 和 HARD_FAULT_N 应接近 3.3 V。
- nSLEEP 应在约 1 ms RC 后升到至少 `2.6 V`；断开 SJ_WAKE 后应回到 0 V。
- 六个 U1 侧 PWM 应为 0 V。
- 记录 3V3 供电电流并摸查 U1 是否反向灌电发热；3V3 单独上电异常时不加 VM。

若 3V3 电流超限或任一默认态不对，不加 VM。

## 4. 首次 VM 静态上电

保持 DRVOFF 高、PWM 全低。先 3V3，再从 J_PWR 输入限流电源，调高 `VM_RAW` 直到 TP_VM=`5.0 V`，限流 `50 mA`；不要接电机/假负载。后续所有母线数字也都以 TP_VM 为准，台源读数需补偿 SS56 压降。

除顺序上电外，再用示波器做一次 VM/3V3 同时及错相上电：同时观察 nSLEEP、DRVOFF、任一高/低 PWM 与对应 OUT，相输出不得出现有效导通毛刺。

依次测：

| 点 | 预期 |
| --- | --- |
| VM | TP_VM=`5.0 V`；VM_RAW 比它高一个 D1 压降 |
| AVDD | `3.1–3.465 V` |
| VREF | 接近 AVDD |
| CP−VM | 约 `3.6–5.25 V`，以数据手册范围为准 |
| SOA/B/C | 稳定在 AVDD/2 附近 |
| V_LOW | 约 `0.573/3.3×AVDD` |
| V_HIGH | 约 `2.727/3.3×AVDD` |
| VBUS_SENSE | 约 VM/6 |
| HARD_FAULT_N | 唤醒期间允许短暂低，稳定后应高 |
| OUTA/B/C | DRVOFF 高时高阻，不应主动开关 |

记录总电流和 U1/D1/TLV1704 温度。任何持续 nFAULT、AVDD 不稳、CP 异常、输出开关或发热，立即断 VM。

## 5. SPI 与固件关断态

按 [控制接口表](CONTROL_HEADER_PINOUT.csv) 接 STM32；GND 先接、3V3 次之、信号最后接。VM 仍 5 V/50 mA，DRVOFF 保持高。

产品固件当前应继续显示工厂编码器 `PENDING_VENDOR`，禁止 arm、MOE 关闭。这不是失败。应验证：

- SPI Mode 1、5 MHz、16 bit 帧波形正确。
- 可配置并回读 `CTRL2=0x68`、`CTRL3=0x5F`、`CTRL4=0x10`、`CTRL5=0x02`、`CTRL6=0x01`、`CTRL10=0x00`。
- `CTRL6 bit0=1` 后 Buck 被禁用，但板上 22 Ω/22 µF 仍保留。
- STAT0/1/2 无未知故障；DRVOFF 高、TIM1 MOE 低。

SPI 不通时先查 CS 极性、Mode 1、16 bit、GND 和线长，不先改寄存器表。

## 6. 比较器逐路注入

不接电机。断电后拆掉对应 `R_SOx_LINK` 0 Ω，再上 3V3 和 5 V VM，从 SOx_FANOUT 用低阻源注入。每次只测一相：

先测并记录本板实际 AVDD，不要假定恰好 3.300 V：

1. 注入 `0.50×AVDD`：HARD_FAULT_N 应高。
2. 注入 `0.20×AVDD`、`0.80×AVDD`：不应触发。
3. 缓慢向下扫，记录 HARD_FAULT_N 下降点；首板电阻计算目标为 `21/121×AVDD`，即 `0.17355×AVDD ± 25 mV`。
4. 缓慢向上扫，记录下降点；首板电阻计算目标为 `100/121×AVDD`，即 `0.82645×AVDD ± 25 mV`。
5. 在阈值附近小幅往返，示波器记录 HARD_FAULT_N 是否抖动；第一次低电平后 TIM1 MOE 必须保持关闭，不能自动重新使能。
6. 对 A/B/C 六个比较器重复；同时核对 STM32 PB12 和 TIM1 BIF。

测完断电并把三个 0 Ω 恢复。禁止在 0 Ω 未拆时用强驱动源硬灌 SO_RAW。

母线 16 V 比较器先不要直接把整板升到 16 V。先测本板 `3V3_CTRL` 和 `VBUS_TRIP`；在 VM=5 V 时用带电流限制的低阻源直接驱动 `VBUS_DIV_RAW` 到 `VBUS_TRIP−50 mV`/`VBUS_TRIP+50 mV`，确认前者释放、后者拉低。再用可限流 VM 缓慢升压做一次真实交叉验证，记录实际阈值，并与 `VM_TRIP=6×VBUS_TRIP` 对照。目标是 `15.5–16.5 V`；超出该区间就在任何有功率测试前重配 23.7 kΩ 阈值电阻。18 V 只是 DRVOFF 高、输出 Hi-Z 的停止上限，不是运行点。

## 7. 无电机假负载

只有在以下条件全部满足后进行：SPI/静态/注入均通过；工厂编码器后端 `control_ready=true`；电角零位有效；产品固件没有安全绕过。

三只 `10 Ω/50 W` 低感电阻接成浮置星形：三个外端分别接 OUTA/B/C，星点不接 GND。固定到散热板。电源从 `9 V/0.2 A` 限流开始。

示波器检查：40 kHz、六路互补关系、实际死区、OUTA/B/C、SOA/B/C、ADC_SAMPLE_TRIG、HARD_FAULT_N。任何相位同时导通、过冲接近器件额定、SOx 饱和、nFAULT 或异常温升立即停止。

当前编码器仍 PENDING 时，只完成关断态、SPI、ADC 零点、比较器和 BKIN 输入验证；不能为了“今天看到 PWM”加入隐藏 bench bypass。

## 8. 实电机推进顺序

0. 驱动板不接电，先完成 [GL30 到货基线](../motor-control/GL30_KV290_ARRIVAL_BASELINE_CN.md) 中的机械手感、三组线间电阻和万用表级对壳低阻排查；闭环前必须确认编码器供电/线序。线间电感和手转反电势属于推荐辨识项，没有仪器时允许延期，并继续使用厂家 `330 uH`、低带宽 PI 和低电流阶梯；任何已测项目明显不对称都先停在被动检查。
1. 空载牢固固定电机，9 V/0.2 A；先确认编码器方向和 7 极对，再标定电角零位。若 0.2 A 不能可靠对齐，只允许短时升到 0.3 A，并记录持续时间和温升。
2. 小幅 q 轴电流，核对三相电流符号/增益和转矩方向；用已知电流测出三相 CSA 实际零点和增益，再把实测 V_LOW/V_HIGH 换算为动作电流。
3. 逐级把限流升到 0.5 A、1.0 A、1.6 A；每级记录 U1、D1、连接器和 PCB 温升。若任一相实测硬件动作点低于约 `1.65 A`，在有功率升流前先把软件软限流降到 `1.5 A`，或按实测增益重配阈值电阻，不能让两个限制在公差区互相打架。
4. 注入 nFAULT/BKIN/通信断线/编码器断线，测触发到相输出关断延迟；故障后不得自动重新使能。
5. 最后才测快速拨动与回灌；验证板没有 14.4 V 制动电阻时，必须用低能量、限速和可吸收电源，不能把 TVS 当制动器。

厂家表中的 `2.13 A / 0.08 N·m` 额定点和 `7.4 A / 0.28 N·m` 峰值点目前都只是供应商数据，尚未在这只样机上复测。当前 `1.6 A` 软件软限流、`1.75 A` 软件硬限流和名义约 `1.8 A` 的验证板硬件窗口是有意设置的安全边界；硬件窗口计入器件公差后粗估为 `1.47–2.17 A`，必须先实测再放行 1.6 A。当前方案不支持验证 7.4 A 峰值；如未来确需峰值能力，必须另做功率级、母线回灌、热容量和退磁风险设计。

## 9. 哪些结论能带到正式版

可以带走：接口方向、SPI 寄存器、CSA 标度、比较器实际阈值、BKIN 极性/延迟、初始死区、低压波形、功率器件温升趋势和测试方法。

不能直接带走：最终铜厚/尺寸、外壳内温升、EMI、连续 2 A 能力、真实再生制动、工厂编码器接口、电角零位、认证和量产良率。正式产品板仍需按相同门重新测，不得用验证子板结果代替。

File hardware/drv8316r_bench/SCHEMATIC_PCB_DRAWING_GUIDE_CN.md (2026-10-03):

# GL30 DRV8316R 验证子板：原理图与 PCB 画法

## 0. 先锁住这五条

1. 只用 `DRV8316RRGFR`（SPI 版），不能用 `DRV8316T`。
2. `SW_BK/FB_BK` 不能因为“不使用 Buck”就悬空；必须画 `22 Ω + 22 µF` 的 Resistor Mode 外围，固件再写 `BUCK_DIS=1`。
3. `DRVOFF` 高有效关断，必须 `10 kΩ` 上拉；六路 PWM 必须各 `100 kΩ` 下拉。
4. DRV 的内部 OCP 不是本项目约 `2 A` 的可测过流层。三路 SOx 必须各有上下限比较器，全部开漏线与到 `HARD_FAULT_N/TIM1_BKIN`；首板阈值名义取 `±1.8 A`。
5. 工厂编码器已确认为 `AS5048A + SPI`；它属于电机侧独立组件，本子板不画编码器接口，也不为了出 PWM 修改产品固件的安全门。

SOA/B/C 是 DRV8316 内部低侧 FET 电流检测的输出，数据手册给出约 1 µs 的建立时间。外部比较器能在 SOx 有效时异步送入 TIM1 BKIN，但不是覆盖所有开关状态的独立分流器；DRV 内部 OCP 仍承担快速短路保护，ADC 采样仍必须与 PWM 有效窗口同步。

## 1. 芯片作用、选型理由与职责边界

### 1.1 验证子板本体

验证子板只有两种集成电路、共三颗 IC。肖特基二极管、TVS、保险丝和电阻电容属于分立器件，不计入芯片数量。

| 位号 | 芯片 | 数量 | 主要作用 | 为什么选择 | 明确不负责 |
| --- | --- | ---: | --- | --- | --- |
| U1 | `DRV8316RRGFR` | 1 | 三相集成功率级、电荷泵、三路电流检测、SPI 配置与驱动器保护 | 适配 12 V GL30；集成功率 MOSFET 和无外部分流器的电流检测，体积和外围数量小；R 版本有 SPI 诊断，适合 6-PWM FOC 与首板排错 | FOC 运算、编码器读取、电池充电、无线通信、整机约 2 A 产品限流 |
| U2、U3 | `TLV1704AIPWR` | 2 | 七路独立模拟阈值判断：三相电流上下窗口共六路，母线过压一路 | 单颗四比较器、2.2–36 V 供电、开漏输出、传播延迟约 560 ns 典型值；两颗提供八路，覆盖七个故障条件并保留一单元 | 测量电流数值、替代 DRV 内部短路 OCP、代替 MCU 记录和故障归因 |

`DRV8316R` 是本板核心。它把控制器的低功率控制量转换成三相功率输出，并提供电流观测与故障状态。选择集成功率级而不是“栅极驱动器 + 六颗外置 MOSFET”，是为了让首板把重点放在 FOC、采样、保护和布局验证上，减少功率器件选型与栅极回路变量。选择 R 版而不是 T 版，是因为 SPI 配置和可读故障信息对验证板有直接价值。

本板按当前 `1.6 A` 软件工作上限和首板约 `±1.8 A` 名义硬件窗口验证，不以释放电机厂家给出的 `7.4 A` 峰值为目标。电机峰值能力不能反推本验证板的连续电流、散热或保护能力。

`TLV1704` 是独立于 CPU 运算的板级阈值判断层。使用两颗是因为三相各需要上、下限两个判断条件，再加一个母线过压条件，共七路。它与 DRV 内部 OCP 分工：DRV 内部 OCP 处理快速短路和器件自保，外部比较器验证项目自己的电流窗口与母线停止边界。

### 1.2 与验证子板协同、但不安装在本板的芯片

| 芯片 | 所在位置 | 主要作用 | 为什么选择 | 与验证子板的边界 |
| --- | --- | --- | --- | --- |
| `STM32G474` | 当前在 NUCLEO-G474RE；正式产品使用 STM32G474 系列 | 运行 FOC、电流环和手感算法；生成 6-PWM；同步采样；处理硬件 Break、SPI 和安全状态 | 高级定时器、同步 ADC、硬件 Break、Cortex-M4F 与 CORDIC/FMAC 适合确定性的实时电机控制；CubeMX 和 LL 支持成熟 | 控制器不放在子板，子板只暴露可验证的驱动、采样和故障边界 |
| `AS5048A` | GL30 厂家编码器底座/小板 | 提供 14 位绝对机械角度、SPI 数据、奇偶校验和磁场诊断 | 厂家已经完成磁钢、底座和传感器装配；绝对角度无需先寻找机械零点；SPI 延迟和诊断能力适合 FOC | 编码器直接属于控制器侧输入，不占用 DRV8316R 子板面积；仍需验证方向、连续性、诊断状态和电角零位 |

NUCLEO 上的 ST-LINK 调试 MCU、USB 接口和板载稳压器只是开发工具基础设施，不属于正式产品电机控制功能，也不应复制到本验证子板。

### 1.3 分立器件的职责

- `SS56` 是串联肖特基器件，承担验证板的输入反接隔离；它不是电源管理芯片，压降和温升必须实测。
- `SMBJ18A` 是 TVS，只吸收瞬态尖峰；它不能吸收持续再生能量，也不是 16 V 运行钳位器。
- `F1` 是板级灾难故障和线束保护；它不能替代 DRV OCP、外部电流窗口或实验电源限流。
- 电阻电容承担去耦、滤波、阈值、阻尼和上电默认态；它们的数值是首板输入，不是量产实测结论。

### 1.4 建议的数据手册学习重点

| 芯片 | 先读内容 |
| --- | --- |
| DRV8316R | Functional Block Diagram、Device Functional Modes、Current Sense Amplifiers、SPI Registers、Protection Features、Layout Guidelines |
| TLV1704 | Input Common-Mode Range、Open-Collector Output、Propagation Delay、Output Low Voltage、Power-On Behavior |
| STM32G474 | TIM1 互补 PWM/死区/Break、ADC 触发与采样时序、SPI、DMA、CORDIC/FMAC |
| AS5048A | SPI 帧与奇偶校验、ANGLE、ERRFL、DIAAGC、MAGNITUDE、磁钢位置要求 |

## 2. 工程页怎么分

建议建 5 张原理图页，网络名完全照本文件，不要用 `Net-(...)` 自动名：

1. `01_POWER_PROTECTION`：输入、保险丝、反接、TVS、bulk、VM 去耦。
2. `02_DRV8316R_CORE`：U1、charge pump、Buck 必需外围、AVDD/VREF、三相输出。
3. `03_CONTROL_INTERFACE`：2×10 控制头、6PWM、SPI、nSLEEP、DRVOFF。
4. `04_CSA_HARD_FAULT`：SOx 两条支路、两片 TLV1704、阈值与线与故障。
5. `05_TESTPOINTS_MECHANICAL`：测试点、安装孔、装配说明和 PCB 约束。

先画完每页并逐网复核，再开始 PCB。不要边画原理图边随意换网络名。

从第一张图开始就只放同一个 `GND` 电源符号。下文写的 AGND、PGND、GND_BK 是芯片引脚名或“安静/功率回流区域”提示，不是让你创建三个不同的网络；PCB 也不使用 NetTie 或切地。

## 3. 第 1 页：电源与保护

按下面顺序连接：

```text
J_PWR.1 (VM_RAW)
  -> F1 3 A 延时型保险丝
  -> D1 60 V / 5 A 串联肖特基（正向朝 VM）
  -> VM

J_PWR.2 -> GND
VM -> D_TVS SMBJ18A -> GND（阴极接 VM，阳极接 GND）
VM -> 470 uF / 50 V -> GND
VM -> 10 uF / 50 V X7R -> GND
VM -> 1 uF / 50 V X7R -> GND
```

建议 D1 用 `SS56`/SMB 或相当的 60 V、5 A 器件，周围留散热铜。它在 2 A 时可能耗散约 `0.6–1 W`，首板必须测温；它也会吃掉低压余量，因此 `5 V` 只用于 DRVOFF 高、输出 Hi-Z 的静态验证，有功率运行从 `6 V` 以上开始。正式产品若连续电流较大，再根据实测改成 60 V P-MOS/理想二极管，验证板不要先增加复杂度。

`SMBJ18A` 只处理有源钳位条件下的瞬态，不是 14.4 V 再生制动，也不代替 16 V 比较器。本文所有 5/6/15.5/16/18 V 边界都指 D1 后、TP_VM 测得的 `VM`，台源接在 `VM_RAW` 时设定值要再加 D1 的实测压降。有功率运行范围锁到 `6.0–15.5 V`；约 16 V 时本来就应由硬件比较器拉低 BKIN，18 V 只用于 DRVOFF 高、输出 Hi-Z、台源限流条件下确认阈值和耐受，不能在 18 V 下要求电机继续运行。TP_VM 高于 18 V 不在本板验收范围。

470 µF 的上电浪涌不是 3 A 保险丝可自动忽略的小事：F1 必须选有明确 `I²t` 的延时型，首次上电必须用限流电源缓升；保险丝只保护线束/板级灾难故障，不替代半导体过流保护。

U1 附近再放 3 只 `100 nF / 50 V / 0603`，分别从 9、10、11 三个 VM 引脚就近回到最近的 PGND。bulk 的负端要直接回到 U1 的功率地回路，不要绕过控制区。

J_PWR 建议用额定至少 `5 A` 的 2Pin/5.08 mm 端子，J_MOTOR 用同系列 3Pin/5.08 mm 端子。原理图上把 `VM_RAW`、`VM` 和极性写在连接器旁，PCB 正反面都要有 `+/-` 与 `A/B/C` 丝印；不要依赖装配图才能判断方向。

## 4. 第 2 页：DRV8316R 核心

### 4.1 自建符号与封装

U1 使用 TI `RGF0040E`：VQFN-40，`5.0 mm × 7.0 mm`，脚距 `0.5 mm`，外周推荐焊盘约 `0.25 mm × 0.60 mm`，中心裸露焊盘为 41 脚、约 `3.5 mm × 5.5 mm`。必须逐项对照本目录的 TI 数据手册封装页，不能从相似 QFN 猜封装。

中心 41 脚是热焊盘/AGND，不是 PGND。建议在热焊盘内布 `Ø0.20–0.30 mm` 成品孔的热过孔阵列，并按工厂能力做底面盖油或填孔，防止回流时吸锡。钢网中心窗按 TI stencil 页分成多个小窗，总开口不要做成一整块，否则 U1 容易漂浮和桥连。

### 4.2 U1 引脚逐项连接

| U1 脚 | 名称 | 连接 |
| ---: | --- | --- |
| 1 | NC | 明确 No Connect |
| 2 | AGND | AGND/热焊盘地 |
| 3 | FB_BK | 接 RBK 后端与 CBK 正端 |
| 4 | GND_BK | 接 CBK 负端，再低阻回 GND |
| 5 | SW_BK | 经 `22 Ω` 接 FB_BK |
| 6 | CPL | 接 47 nF 飞跨电容一端 |
| 7 | CPH | 接 47 nF 飞跨电容另一端 |
| 8 | CP | 经 `1 µF/16 V` 接 VM |
| 9,10,11 | VM | VM 宽铜；每组就近 100 nF 回 PGND |
| 12 | PGND | 功率地 |
| 13,14 | OUTA | 合并后到 J_MOTOR.1 |
| 15 | PGND | 功率地 |
| 16,17 | OUTB | 合并后到 J_MOTOR.2 |
| 18 | PGND | 功率地 |
| 19,20 | OUTC | 合并后到 J_MOTOR.3 |
| 21 | DRVOFF | `10 kΩ` 上拉到 3V3_CTRL，并接 J_CTRL.13 |
| 22 | nFAULT | 直接加入 HARD_FAULT_N 开漏线与，并留测试点 |
| 23 | nSLEEP | 接延时唤醒网络与 J_CTRL.19 |
| 24 | NC | 明确 No Connect |
| 25 | AVDD | `1 µF/6.3 V X7R` 就近到 AGND；留 TP_AVDD |
| 26 | AGND | AGND/热焊盘地 |
| 27 | INHA | 47 Ω 后的驱动侧网络 INHA_DRV |
| 28 | INLA | INLA_DRV |
| 29 | INHB | INHB_DRV |
| 30 | INLB | INLB_DRV |
| 31 | INHC | INHC_DRV |
| 32 | INLC | INLC_DRV |
| 33 | SDO | J_CTRL.10 / MISO |
| 34 | SDI | 22 Ω 后的 MOSI_DRV |
| 35 | SCLK | 22 Ω 后的 SCK_DRV |
| 36 | nSCS | J_CTRL.12 / CS_N，10 kΩ 上拉 |
| 37 | VREF/ILIM | 0 Ω 接 AVDD；`100 nF/6.3 V` 就近到 AGND |
| 38 | SOC | SOC_RAW |
| 39 | SOB | SOB_RAW |
| 40 | SOA | SOA_RAW |
| 41 | Thermal pad | AGND；焊接到顶层地铜并用热过孔连接大面积地 |

### 4.3 不使用 Buck 时仍必须画的电路

```text
SW_BK -- RBK 22 Ω -- FB_BK
FB_BK -- CBK 22 µF / 10 V X5R/X7R -- GND_BK
```

DRV8316R 复位后 Buck 默认开启；产品固件写 `CTRL6=0x01` 才置 `BUCK_DIS=1`。因此上面两件元件既不能 DNP，也不能把 SW_BK/FB_BK 悬空。RBK、CBK 紧贴 U1，SW_BK 与 FB_BK 走线之间用地隔开，不要靠近 SOx/VREF。

## 5. 第 3 页：控制接口

2×10、2.54 mm 控制头固定如下；与 [CSV 表](CONTROL_HEADER_PINOUT.csv) 保持一致：

```text
1  3V3_CTRL      2  GND
3  INHA          4  INLA
5  INHB          6  INLB
7  INHC          8  INLC
9  SCK          10  MISO
11 MOSI         12  CS_N
13 DRVOFF       14  HARD_FAULT_N
15 SOA_ADC      16  SOB_ADC
17 SOC_ADC      18  VBUS_SENSE
19 nSLEEP       20  GND
```

六路 PWM 每路画成：

```text
J_CTRL.INx -> 47 Ω -> INx_DRV -> U1
                       |
                     100 kΩ
                       |
                      GND
```

SPI：SCK 和 MOSI 各串 `22 Ω`，电阻靠发送端；在子板上先靠近控制头放。MISO 直连，CS_N 用 `10 kΩ` 上拉到 3V3_CTRL。首板线束短于 10 cm；若飞线更长，5 MHz SPI 失败先缩短线，不先改寄存器。

nSLEEP 画成：

```text
3V3_CTRL -> SJ_WAKE（默认闭合） -> 10 kΩ -> nSLEEP
nSLEEP -> 100 kΩ -> GND
nSLEEP -> 100 nF -> GND
```

这个约 1 ms 的延时让 `nFAULT/HARD_FAULT_N` 的 2.2 kΩ 上拉先超过 2.2 V，再唤醒 DRV，避免 TI 数据手册所述的内部 test-mode 风险。DRV8316R 的 nSLEEP 内部还有约 `150–300 kΩ` 下拉；即使把它和外部 100 kΩ 一起按最坏值计算，3V3_CTRL=`3.1 V` 时稳态仍约 `2.66 V`，高于 nSLEEP 保证高阈值 `1.6 V`。断开 `SJ_WAKE` 后，外部和内部下拉把 nSLEEP 固定为低，整片睡眠。

3V3_CTRL 只给逻辑上拉和唤醒使用，不能给 VM 供电，也不与 AVDD 硬并联。推荐时序是先接 MCU/3V3，再接 VM；断电反过来。

## 6. 第 4 页：CSA 与硬件故障链

### 6.1 三路 SOx

每相完全复制一份，禁止共用串联电阻：

```text
SOx_RAW -> 0 Ω 可拆链接 -> SOx_FANOUT

SOx_FANOUT -> 1 kΩ -> SOx_ADC -> J_CTRL
                           |
                          33 pF
                           |
                          AGND

SOx_FANOUT -> 1 kΩ -> SOx_CMP -> 两个窗口比较器输入
                           |
                         100 pF
                           |
                          AGND
```

正常时装上 0 Ω。做比较器/ADC 注入时先断电拆掉对应 0 Ω，再从 `SOx_FANOUT` 测试点注入，避免外部源硬顶 U1 的 SO 输出。

### 6.2 阈值

用 `0.1%` 电阻从 AVDD 生成两个跟踪 VREF 的阈值：

```text
AVDD -- 100 kΩ -- V_LOW  -- 21.0 kΩ -- AGND
AVDD -- 21.0 kΩ -- V_HIGH -- 100 kΩ -- AGND
V_LOW、V_HIGH 各加 10 nF 到 AGND
```

名义值：

```text
V_LOW  = 3.3 × 21.0 / (100 + 21.0) = 0.573 V
V_HIGH = 3.3 × 100 / (21.0 + 100) = 2.727 V
I = (VSO - AVDD/2) / 0.6
```

所以典型值约为 `−1.80 A / +1.80 A`。阈值跟随 AVDD，不能改成固定 0.573/2.727 V 的独立廉价基准后又继续按 AVDD/2 换算。

这个数不是“保证 1.8 A 动作”。DRV8316R 数据手册给出的 CSA 增益误差在小于 4 A、全温范围可到 `±10.5%`，等效输入偏置约 `±50 mA`；再把 AVDD=`3.1–3.465 V` 和 TLV1704 全温输入失调约 `±5.5 mV` 放入保守计算，首板固定阈值的实际动作电流粗略可能落在 `1.47–2.17 A`，电阻误差还会增加少量偏差。之所以不用名义 2.0 A，是因为它最坏可能接近 2.4 A 才动作；也不用名义 1.7 A，是因为它更容易早于当前 1.6 A 软件限制动作。首板先装 `100 kΩ/21.0 kΩ`，上电后先在低电流区测每相零点、增益和实际比较器电压阈值，再决定是否升到 1.6 A；必要时只换阈值电阻或先把软件软限流降到 1.5 A。正式版必须根据实测和温度目标重新算，不能把首板阻值当量产保证。

### 6.3 TLV1704 单元分配与极性

U2、U3 均锁定 `TLV1704AIPW`（PW/TSSOP-14）开漏四比较器，VM 供电，GND 回安静地；每片供电脚旁放 `100 nF/50 V`，两片附近再共享 `1 µF/50 V`。TI 给出的约 560 ns 是典型传播延迟而非保证最大值，首板必须测“模拟越界→HARD_FAULT_N→PWM 关断”的总延迟。

PW 封装的物理脚固定为：`V+=3`、`V−=12`；通道 1 为 `OUT=2/IN−=4/IN+=5`，通道 2 为 `OUT=1/IN−=6/IN+=7`，通道 3 为 `OUT=14/IN−=8/IN+=9`，通道 4 为 `OUT=13/IN−=10/IN+=11`。下表的 A/B/C/D 对应通道 1/2/3/4；如果 EDA 库的单元字母不是这个顺序，以物理脚号为准逐个改，禁止只凭单元字母连线。

| 单元 | `IN+` | `IN−` | 何时拉低 HARD_FAULT_N |
| --- | --- | --- | --- |
| U2A | SOA_CMP | V_LOW | SOA < V_LOW |
| U2B | V_HIGH | SOA_CMP | SOA > V_HIGH |
| U2C | SOB_CMP | V_LOW | SOB < V_LOW |
| U2D | V_HIGH | SOB_CMP | SOB > V_HIGH |
| U3A | SOC_CMP | V_LOW | SOC < V_LOW |
| U3B | V_HIGH | SOC_CMP | SOC > V_HIGH |
| U3C | VBUS_TRIP | VBUS_DIV_RAW | VM > 约 16 V |
| U3D | AVDD | AGND | 输出 NC，固定状态不参与故障链 |

U2A–U3C 的 7 个开漏输出、U1 `nFAULT` 全部直接连接为 `HARD_FAULT_N`，只放一只 `2.2 kΩ` 上拉到 3V3_CTRL，不加 RC，不反馈到 DRVOFF。该网络接 J_CTRL.14 和 STM32 `PB12/TIM1_BKIN`。

首板不画模拟正反馈滞回：PB12 第一次变低即由 TIM1 硬件清除 MOE，自动恢复关闭，功率级不会因为比较器随后释放而在阈值附近反复开关。不要从共用的 `HARD_FAULT_N` 反馈到七个比较器输入，那会把各故障源耦合在一起。代价是阈值附近可能出现安全侧误触发或故障线抖动，必须在注入测试中测边沿、抖动和 BIF/MOE 锁存；若实板确有问题，再按单个比较器的波形设计独立滞回，而不是在共用线上随意加 RC。

TIM1 BKIN 首板保持官方工程当前的低有效、`Filter=0`、`AutomaticOutput=DISABLE`。不先加数字滤波，是因为同一根线还承载 nFAULT 和真实过流脉冲；滤波会增加或隐藏关断延迟。若实板出现安全侧误锁，先查布局、探头地、SOx 采样窗口和比较器输入波形，再依据实测决定独立滞回或最小滤波时间。

TLV1704 数据手册在 4 mA 条件给出的输出低电平最坏值可接近 0.9 V；本电路 2.2 kΩ/3.3 V 约为 1.5 mA，但仍要在每个故障源逐项拉低时测量。首板验收目标 `HARD_FAULT_N < 0.8 V`，并同时核对 STM32 PB12 确认识别为低；不满足时先根据实测调整上拉和布线，不能在固件里反转/放宽故障极性。

### 6.4 母线采样和 16 V 比较器

```text
VM -- 100 kΩ/0.1% -- VBUS_DIV_RAW -- 20.0 kΩ/0.1% -- AGND
VBUS_DIV_RAW -> 1 nF -> AGND
VBUS_DIV_RAW -> U3C IN-
VBUS_DIV_RAW -> 1 kΩ -> VBUS_SENSE/J_CTRL.18
VBUS_SENSE -> 1 nF -> AGND

3V3_CTRL -- 23.7 kΩ/0.1% -- VBUS_TRIP -- 100 kΩ/0.1% -- GND
VBUS_TRIP -> 10 nF -> AGND
VBUS_TRIP -> U3C IN+
```

名义上 `VBUS_DIV_RAW=VM/6`，3V3_CTRL=`3.300 V` 时 `VBUS_TRIP≈2.668 V`，相交点约 `16.0 V`。母线阈值特意从独立、受控的 3V3_CTRL 生成，不从 DRV 的 AVDD 生成；电流窗口必须跟随 AVDD/VREF，母线过压不需要跟随。画板前确认控制器 3V3 的稳态精度，首板再按 `VM_TRIP=6×3V3_CTRL×100/(23.7+100)` 实测并换 23.7 kΩ。首板没有模拟迟滞；故障由 BKIN/软件锁存，避免阈值附近自动重复使能。若实测噪声造成静态误触发，再依据波形计算迟滞，不能先凭感觉加大电容。

首板不在 VBUS_SENSE 上加到 3V3_CTRL 的外部钳位，避免 MCU 掉电时经钳位二极管反灌 3V3；100 kΩ 上臂负责限制异常注入电流，但它不等于“绝对不会反灌”。必须把 `VM≤18 V` 写在电源口丝印，并在只有 VM、只有 3V3、VM 先上和同时上电四种情况下测 3V3_CTRL、VBUS_SENSE 与 MCU 供电电流。若 MCU 数据手册的注入电流限制或实测不满足，停止测试后再加对地低漏电钳位/缓冲，不能直接把二极管接到 3V3 电源轨。

## 7. 第 5 页：测试点与机械

### 7.1 子板必须保留的测试点

测试点的目的不是“每根线都能夹”，而是让电源、时序、采样、阈值和故障链能够被分段证明。按以下功能分组，不能只在连接器上临时飞线代替。

| 功能组 | 必须观察的网络 | 用途 | 特别注意 |
| --- | --- | --- | --- |
| 输入与偏置电源 | `VM_RAW`、`VM`、`3V3_CTRL`、`AVDD`、`VREF`、`GND` | 检查上电顺序、保护器件压降、内部偏置、零电流中心点 | VM 与逻辑地附近都要有就近 GND；AVDD/VREF 使用小环路探测 |
| DRV 电荷泵与 Buck | `CP`、`CPH`、`CPL`、`SW_BK`、`FB_BK` | 判断电荷泵和复位默认开启的 Buck 是否工作、是否存在异常纹波 | `CPH-CPL` 优先差分观察；SW_BK 是高 dv/dt 节点，禁止长地夹 |
| 控制与诊断 | 六路 `INx_DRV`、`SCK_DRV`、`MISO`、`MOSI_DRV`、`CS_N`、`DRVOFF`、`nSLEEP`、`HARD_FAULT_N` | 核对 PWM 频率、互补关系、死区、SPI 帧、默认关断和故障响应 | 高速测试点旁放相邻 GND 小焊盘；不使用长引线测试环制造额外串扰 |
| 三相电流观测 | 三路 `SOx_RAW`、`SOx_FANOUT`、`SOx_ADC`、`SOx_CMP` | 区分 DRV 原始输出、注入节点、ADC 滤波结果和比较器看到的波形 | 三相保持完全对称；注入只在断电并断开对应 0 Ω 隔离后进行 |
| 电流和母线阈值 | `V_LOW`、`V_HIGH`、`VBUS_DIV_RAW`、`VBUS_SENSE`、`VBUS_TRIP` | 标定实际动作阈值，区分分压、ADC 与比较器误差 | 这些是安静模拟节点，远离相节点和 SW_BK，测试焊盘不能形成长支线 |
| 三相功率输出 | `OUTA`、`OUTB`、`OUTC` | 检查相节点占空比、死区、过冲、振铃和停机状态 | 只用合适耐压的差分探头或严格确认接地方式；禁止把接地示波器地夹直接夹到任一相节点 |

原理图使用以下统一测试点网络名：

```text
VM_RAW, VM, GND, 3V3_CTRL, AVDD, VREF,
CP, CPH, CPL, FB_BK, SW_BK,
INHA_DRV, INLA_DRV, INHB_DRV, INLB_DRV, INHC_DRV, INLC_DRV,
SCK_DRV, MISO, MOSI_DRV, CS_N, DRVOFF, nSLEEP, HARD_FAULT_N,
SOA_RAW, SOB_RAW, SOC_RAW,
SOA_FANOUT, SOB_FANOUT, SOC_FANOUT,
SOA_ADC, SOB_ADC, SOC_ADC,
SOA_CMP, SOB_CMP, SOC_CMP,
V_LOW, V_HIGH, VBUS_DIV_RAW, VBUS_SENSE, VBUS_TRIP,
OUTA, OUTB, OUTC
```

### 7.2 外部控制器与编码器需要预留、但不放在本子板的测试点

| 所在部分 | 建议保留 | 用途 |
| --- | --- | --- |
| STM32 控制器/Nucleo 侧 | `3V3`、`GND`、`NRST`、`SWDIO`、`SWCLK`、`ADC_SAMPLE_TRIG`、`TIM1_BKIN` | 下载与复位、确认 ADC 采样时刻、测量硬件故障到 PWM 关闭的延迟 |
| AS5048A 线束或正式主板编码器口 | `5V_ENC`、`GND`、`ENC_CSN`、`ENC_CLK`、`ENC_MOSI`、`ENC_MISO` | 检查供电、SPI 时序和电机运行时的通信抗干扰 |

AS5048A 的磁场强弱、自动增益、错误状态和角度连续性主要通过寄存器记录验证，不需要为磁钢设置电气测试点。编码器测试焊盘属于控制器或线束转接侧，不得为了方便测量把编码器信号绕进功率子板。

### 7.3 不需要单独增加测试点的部分

- U1 重复的 VM、PGND 和双 OUT 封装脚不逐脚设置测试点，验证对应功能网络即可。
- NC 脚、每颗去耦电容的两端、普通上拉/下拉电阻两端不重复设置测试点。
- 七个比较器开漏输出已经汇总到同一故障网络，不为每个输出增加“看似独立、实际同网”的焊盘；逐路验证依靠各自输入注入点和共同故障线。
- 同一高速信号不在串联阻尼电阻前后各放长测试支线；优先观察器件侧实际波形。
- 不因已有连接器就删除关键测试点；连接器针脚不等于适合示波器探测的低环路测量位置。

### 7.4 测试点封装与摆放注意事项

- VM、3V3、AVDD、VREF 和慢速阈值可用可夹探头的环形测试点；高速和高 dv/dt 网络优先使用小 SMD 焊盘与相邻 GND 焊盘。
- 每个高速功能组至少放一个紧邻的 GND 探测焊盘，供短弹簧地或差分探头使用；不能让探头地线跨过功率区。
- `OUTA/B/C` 测试点放在功率区边缘，远离控制排针，周围留出差分探头接触和防短路间距。
- SOx 注入点要能明确区分 RAW、FANOUT、ADC 与 CMP，丝印不能只写 `SOA` 造成误注入。
- 测试点支线不得插在去耦电容和芯片引脚之间，也不得扩大 VM—功率桥—PGND 或电荷泵的高频环路。
- 丝印同时给出网络名、故障极性和 `VM≤18 V` 边界；板边测试点保持方向一致，避免翻板后误判相序。

装 4 个 `M3/3.2 mm` 安装孔，孔边到铜/器件留足机械间隙。电源和电机端子放板边，控制头放另一侧，防止示波器夹子跨过相节点。

## 8. PCB 摆放顺序

1. 先放 U1、J_MOTOR、J_PWR、bulk 和 VM 三只 100 nF，锁住功率回路。
2. 把 47 nF 飞跨电容、CP 1 µF、AVDD 1 µF、VREF 100 nF 贴到对应脚旁，优先级高于美观。
3. 放 22 Ω/22 µF Buck 必需外围，远离 SOx/VREF。
4. U2/U3、阈值电阻和 SOx RC 放在 U1 的 SO 引脚一侧；不要穿过 OUTA/B/C 或 SW_BK 下方。
5. 控制头放模拟/逻辑区板边；6PWM/SPI 从控制头平行进入 U1，避免绕相线。
6. 最后放测试点和安装孔，再画铜。

推荐 4 层：

```text
L1：器件、短信号、VM/OUT 局部宽铜
L2：连续 GND 参考/散热面
L3：GND 和低噪声参考为主；必要时仅在功率区放局部 VM 岛
L4：慢信号、局部功率铜和散热面
```

不要做贯穿全板的 VM 内层平面，也不要让 OUTA/B/C 大铜伸到比较器/控制头下方。原理图和 PCB 只使用一个电气网络 `GND`；`PGND/AGND/GND_BK` 是器件引脚名称和布局区域，不是三张彼此隔开的地网。通过元件摆放控制回流路径，L2 保持连续地面；禁止切地、禁止细线/长颈“单点接地”。热焊盘的器件定义是 AGND，但在 PCB 上直接进入同一连续 GND 面并穿多层热过孔。

## 9. 走线与铜规则

- VM、PGND、OUTA/B/C：至少 `1.5–2.0 mm`，优先用短而宽的多边形；端子处可 `3 mm` 以上。
- 普通信号：`0.20–0.25 mm`；SOx/VREF/阈值不与相线长距离平行。
- 电气间距：18 V 板建议不小于 `0.25 mm`，制造能力允许时功率区用 `0.30 mm`。
- 过孔：功率换层用多颗并联；U1 热焊盘使用阵列并与 L2/L3/L4 地铜连通。
- CP–VM、CPH–CPL、AVDD–AGND、VREF–AGND 回路不换层、不打普通信号过孔。
- bulk 回路必须形成 `Cbulk+ -> VM -> U1/相桥 -> PGND -> Cbulk−` 的短闭环。
- 任何测试点支线都不能插在高频去耦电容与 U1 引脚之间。

## 10. 画完后的逐项审图门

满足全部项目才可以发 Gerber：

- U1 料号后缀、顶视图 1 脚和封装 1 脚一致。
- U2/U3 都是 `TLV1704AIPW` 的 PW/TSSOP-14，电源脚 3/12 和四通道物理脚已按数据手册复核。
- 9/10/11 三个 VM、12/15/18 三个 PGND、三组双 OUT 脚没有漏并。
- 41 脚连接 AGND；不是 NC、不是只贴铜不进网络。
- Buck 22 Ω/22 µF 已装，`CTRL6=0x01` 的备注写在图上。
- DRVOFF 的 `10 kΩ` 上拉、六 PWM 的 `100 kΩ` 下拉、CS_N 上拉、nSLEEP 下拉/延时都在 MCU 不运行时有效；没有把 DRVOFF 误用 100 kΩ 与内部下拉形成危险分压。
- nFAULT 与七路比较器确实都是开漏后才能线与；没有推挽输出接入 HARD_FAULT_N。
- 比较器低/高阈值极性逐相检查，没有把 `IN+`/`IN−` 画反。
- V_LOW/V_HIGH 使用 `100 kΩ/21.0 kΩ` 对称网络，图上注明“名义 ±1.8 A、实测后换值”，没有写成保证 2 A。
- VBUS 分压顶端接保护后的 VM，不接 VM_RAW。
- VBUS_TRIP 的 23.7 kΩ/100 kΩ 从独立 3V3_CTRL 生成，不误接 AVDD；图上写出本板实际 3V3 精度和阈值公式。
- 3V3_CTRL 没有与 AVDD 或 VM 直接相连。
- 全板只有一个电气 `GND` 网络；没有误画成互不相连的 AGND/PGND/GND_BK，也没有在连续地层开槽。
- SOx 三路各自有 0 Ω 注入隔离、1 kΩ/33 pF ADC 支路和 1 kΩ/100 pF 比较支路。
- 必须测试点完整覆盖电源、DRV 内部关键节点、六路 PWM、四线 SPI、故障链、SOx 四级观测、阈值和三相输出；高速点旁有短接地焊盘，没有危险的长测试支线。
- AS5048A 测试点只位于控制器或线束转接侧，没有把编码器接口误画到本功率子板。
- DRC 无短路/未布线；ERC 中仅允许经人工确认的 NC/开漏/测试点类提示。
- Gerber、钻孔、坐标、BOM 的板名和版本都只有 `GL30_DRV8316R_BENCH_V1`，不留历史目录。

画好后把 `.kicad_sch`、`.kicad_pcb`、ERC/DRC 报告和正反面截图放回本目录，我可以按本节逐项做第二轮投板审查。

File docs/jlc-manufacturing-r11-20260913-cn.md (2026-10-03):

# R11 嘉立创加工参数与模型

2026-09-13。用户准备向嘉立创询价；两只36齿带轮与两只6901ZZ尚未采购。

- [下载加工参数与模型包](../outputs/r11-jlc-manufacturing/GL30_嘉立创加工参数与模型_R11_20260913.zip)：11种13件STEP、15页加工PDF、3份薄板DXF、总装参照及核对记录。
- [阅读材料、螺纹、表面处理](../outputs/r11-jlc-manufacturing/GL30_嘉立创加工参数与模型_R11_20260913/加工参数_螺纹_表面处理.md)。关键轴孔与隔套尺寸需标准件到货后配作，当前用于询价和工艺审核。
- [当前机械采购简表](mechanical-buy-make-simple-20260913-cn.md)。标准件继续优先，内部金属件本色去毛刺、清洗，不增加装饰处理。

本次修正6种金属件的轴承接触面和孔：内圈接触外径改14.4，外圈接触内径改21.9，轴承座局部钢盾退让及M2/M3螺纹底孔明确化。没有改变外壳、底盖、握环和打印件几何。R10打印件仍可沿用，无新增补打要求；旧R9/R10加工模型由R11替代。

轴承座底部3颗M3×8改用头径6、高1mm薄头，每颗两片0.5mm平垫；9片M3平垫包含轴承座6片与电机3片。原高2mm头加垫后会碰底盖，不能混用。

已核对：13分件有效单实体；179对象总装有效；167个未改对象的导出几何保持；3个DXF单位/外形/孔径正确；新螺钉头在0及0.35mm行程处与底盖无交集，最小CAD距离0.622823mm。

未完成：供应商接单、标准件实测、加工后的真实装配、旋转手感、防松、承载及寿命。没有执行上传、下单或付款。

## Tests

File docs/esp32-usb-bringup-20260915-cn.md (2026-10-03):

# ESP32-S3 USB 实机调试记录（2026-09-15）

用户已连接 Type-C，并授权先烧入固件，晚上再检查实物。本次证据针对这块屏幕板；不继承 STM32、电机、外部灯带或音频的整机验收。

## 已连接的设备与备份

- 本次使用 `COM11`，Espressif USB Serial/JTAG，VID/PID `303A:1001`。没有操作 ST-LINK 的 COM4。
- esptool 识别为 ESP32-S3-PICO-1，revision v0.2；8 MB Flash、8 MB PSRAM，40 MHz 晶振。
- 烧录前读取原始 Flash 全部 8,388,608 字节，保存为 [original-flash-8MB.bin](../outputs/esp32-debug-20260915/original-flash-8MB.bin)。SHA-256：`7DBEB9160BC72C924FCA1DDE727FF877A970C977028D39FEABE361998AB8D6E2`。后续重烧没有覆盖该备份。
- 初次烧录 bootloader、分区表、应用，偏移分别为 `0x0`、`0x8000`、`0x10000`；后续调试仅更新应用。每次均检查 esptool 的数据校验结果。

启动日志确认 PSRAM 自检通过、CPU 240 MHz、CO5300 初始化成功、CST820 初始化成功（ID 183）。这证明驱动初始化与传输链路运行，不等于已经目视确认颜色、裁切、触摸方向或撕裂。

## 实机发现并修正的问题

初版 16 行一段、共 30 段的整帧传输耗时约 294–302 ms。分段计时显示其中 265–274 ms 花在等待传输完成，实际复制约 24 ms。

在当前固定的 ESP-IDF 5.5.1 中，`components/esp_lcd/spi/esp_lcd_panel_io_spi.c` 的 `lcd_spi_post_trans_color_cb` 没有处理用户完成回调返回的唤醒标记。应用只返回 `true`，被唤醒任务仍可能等到下一次 10 ms 系统 tick。修正为回调在信号量释放后显式 `portYIELD_FROM_ISR()`；未修改 SDK 或全局 tick。

只改变上述回调，实机整帧从约 302 ms 降到 50.2 ms，等待总和从约 274 ms 降到 21.9 ms。再启用 `CONFIG_COMPILER_OPTIMIZATION_PERF`，传输约 35.2 ms。保留断言、超时和显示故障锁存；未提高 QSPI 时钟，也未改变任何引脚。

随后将照片的固定遮罩预混入唯一一份 RGB565 资产，非旋转位图按已裁剪的整行复制。主机对比 45 个完整画面，优化前后逐字节一致。静止页面按内容变化请求刷新，表盘秒数变化才重画；计时器、秒表、菜单与动态灯效保留动画请求。

实测仅优化绘制仍会漏掉 100 ms 的短按：最初 USB 测试停在“单击进入菜单”断言。最终把触摸与 USB 接收放入 core 1 的独立 100 Hz 输入任务，通过 64 条定长事件队列携带采样时间。core 0 的 UI 任务独占模型、手势和绘制；批量处理事件时不逐条重画，也不先把模型时钟推进到尚未消费事件的未来。队列丢失事件时取消整段手势，避免伪造单击。

## 最终验收记录

| 验证 | 结果 / 原始证据 |
| --- | --- |
| ESP-IDF 5.5.1 构建 | 通过；[build-input-task.log](../outputs/esp32-debug-20260915/build-input-task.log)，应用 790,416 字节 |
| 应用烧录校验 | `Hash of data verified`；[flash-input-task.log](../outputs/esp32-debug-20260915/flash-input-task.log) |
| 主机 C 回归 | 模型/手势 62 项、RGB565/共享 UI 98 项，共 160 项通过；包含 60 ms 触摸样本回放、双击、旋转后确认 |
| ASan / UBSan | 两组测试通过；[host-sanitized-final.log](../outputs/esp32-debug-20260915/host-sanitized-final.log) |
| 画面一致性 | 45 个整屏 RGB565 画面逐字节一致；[compare-frames.json](../outputs/esp32-debug-20260915/compare-frames.json) |
| 浏览器同源回归 | 41 项通过；[browser-checks-final.json](../outputs/esp32-debug-20260915/browser-checks-final.json) |
| 实机 USB 软件输入 | 20 项通过：单击、双击、循环菜单、33% 音量与零点限幅、计时器运行中调时、秒表、灯效编辑与非法命令拒绝；[完整状态](../outputs/esp32-debug-20260915/usb-ui-smoke-after-input-fix.json) |
| 采样与错误 | 本次操作序列最大采样间隔 10,012 µs；队列丢事件、显示传输错误、触摸读取错误均 0 |
| 内存 | 操作序列 UI 栈最小剩余 840 字节，输入栈 2,536 字节；未见 panic / 看门狗重启 |
| 最终运行状态 | 测试后重新启动，USB 校时收到确认；约 25 秒采样保持表盘、计时器归零、秒表停止、无上述错误；[final-running.log](../outputs/esp32-debug-20260915/final-running.log) |

**性能边界：**整帧传输约 35 ms，不代表整幅界面达到 30 fps。此次复杂页面的一次完整处理/绘制约 0.16–0.26 秒，动画流畅度仍需后续渲染优化；100 Hz 只指输入采样，不能作为显示帧率。此次通过的是软件事件与总线运行验证，实体手指操作尚待用户检查。

本次主机增量构建曾因预览占用 DLL 而链接失败；已修正 `build-host.cmd` 对负返回码的识别，停止对应预览后重新链接，并确认新测试二进制实际执行。Spark 原生子代理在当前账户不可用；新增测试、输入任务及最终集成验收由主线程完成。照片预混资源经独立处理后，由主线程逐帧比对验收。

最终二进制及 ELF 放在 [firmware](../outputs/esp32-debug-20260915/firmware/)；[firmware-manifest.json](../outputs/esp32-debug-20260915/firmware-manifest.json) 包含文件和源码校验值。应用 SHA-256：`836eee9af7cbcc95aac987eb4e8e889dabaf14edfd6bb52538e1c989e9aa60fb`。原始备份独立保留，不与新固件混用。

## USB 调试方式

控制台使用板子的原生 USB，不占 STM32 二进制 UART。命令以换行结束：

| 命令 | 用途 |
| --- | --- |
| `STATUS` | 查询画面、手势/功能状态、内存、帧耗时、触摸读取/错误计数 |
| `TIME <Unix秒>` | 按电脑真实 Unix 时间校时；显示层固定为北京时间 UTC+8 |
| `BUTTON 1` / `BUTTON 0` | 软件模拟按下/释放，经过真实 UI 手势识别 |
| `ROTATE <整数>` | 软件输入 -360 至 360 格的旋转事件 |

后两项只验证软件交互，不证明手指触摸、实体按钮或电机已工作。

可运行下面的只读状态采样和校时工具；先收到 `STATUS` 才发送校时，并检查确认消息，避免刚开机时命令丢失：

```powershell
& 'G:\Agent\.tools\esp-idf-tools\python_env\idf5.5_py3.14_env\Scripts\python.exe' `
  'G:\Agent\GL30-Haptic-Control\firmware-esp32\tools\usb_status.py' `
  --port COM11 --sync-time --samples 3 --interval 2
```

串口号可能随电脑或 USB 接口变化。工具会核对 Espressif VID/PID。一次只开一个串口程序；程序结束会释放串口。UI 自动验收脚本为 [usb_ui_smoke.py](../firmware-esp32/tools/usb_ui_smoke.py)，应在重启到初始表盘后运行，会修改当前 UI 测试状态。

## 断点调试与尚未验证项目

USB 烧录、日志和状态查询已打通。OpenOCD 断点调试尚未打通：实际报告 `LIBUSB_ERROR_NOT_FOUND`。只读检查表明 MI_02 使用 Windows 通用 WinUSB，未注册设备接口 GUID；Espressif 专用驱动包含该注册项。参考 [Espressif 官方说明](https://docs.espressif.com/projects/esp-idf/en/v5.5.1/esp32s3/api-guides/jtag-debugging/configure-builtin-jtag.html)，需要管理员安装相应驱动。本次未修改系统驱动、注册表或执行需要现场 UAC 的安装。

用户当前不在板旁，所以没有声称完成实屏目视和实际触摸验收。晚上检查：表盘照片/中文/时间、单击进菜单、沿边缘滑动换项、双击后退，以及计时器运行中调整。长按仍按此前约定保留。

本记录初次烧录时，断电重启会显示“待校时”。同日后续已增加并实机验证 Type-C 自动校时，详见 [自动校时与 KK_UI 动画使用情况](esp32-auto-clock-and-kk-animations-20260915-cn.md)；本文件上面的二进制哈希和测试数据保留为上一阶段记录。Wi-Fi/NTP 和 RTC 自动校时尚未接入，天气仍为明确标识的示例。STM32/FOC 链路、实体旋钮反馈、外部灯环和真实音频未在本次固件中驱动。

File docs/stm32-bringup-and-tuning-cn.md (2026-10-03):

# STM32 V7 上电、编码器接入与调参手册

2026-10-02 空闲/停止补充：有效零限值 HAPTIC 命令立即撤 arm、清零 FOC、MOE关断并拉高DRVOFF，同时作为通信心跳；它不清故障或绕过 FOC_ALIGN。准备 COMPLETE 且DRVOFF实际为低时，新增共享PB12持续监视与提交前检查；普通停转的DRVOFF高不会被误判。重新启用事务中，MOE与驱动输出均关闭时的释放稳定期由驱动实时读回把关；任何输出指示开启或事务返回后，轮询不再被该标记抑制。见[本轮回归与边界](../outputs/idle-fault-and-link-review-20261002/README_CN.md)；未烧录，实物需分别验证释放/重新启用期间的nFAULT变化和真正故障时的硬件关断。

2026-10-02 采零修订：产品端不再在 DRV8316 休眠时平均 ADC 值。`control/current_zero.c` 在驱动已配置、PB9/nSLEEP 命令与焊盘读回为高、母线有效且桥关闭时，先等待 10 ms，再收集 512 组同步样本；均值必须在 2048±350、每相峰峰值不超过 60 counts。50 ms 是更新时检查的期限，前台每 5 ms 检查缺样超时，并非精确的物理关断时延。休眠、断电或故障会作废零偏，普通停转保留；过压保护不再被采零提前返回跳过。阈值是待实测的工程初值，采零模块 READY 仅表示软件窗口验收通过。详见[采零阶段记录](../outputs/current-zero-review-20261002/README_CN.md)。

同日后续已接入无转矩准备流程：条件满足后 PB9 自动请求母线（100 ms 未建立则失败）；有效 VM 连续监控 10 ms 后 nSLEEP 拉高，等待 10 ms 再配置和采零；最后在 MOE=0、六输入低的条件下释放 DRVOFF、检查驱动，最多确认一次 NPOR。失败关断且不自动重试。启动后的 ADC 缺样由 2 kHz 监督检查 500 µs 新鲜度，不能把门槛当作实际最坏关断延迟。准备完成但电角零位未验证时，整体仍停在 FOC_ALIGN；不会冒充可出力 READY。代码和离线证据见[准备流程记录](../outputs/power-startup-review-20261002/README_CN.md)，此版本尚未烧录。

本页描述 **CET6 产品板端口**。现在手上的 NUCLEO-G474RE + TI DRV8316REVM 请改从 [当前 FOC 联调工程](../firmware-stm32/bench/NUCLEO_G474RE_FOC/README_CN.md) 开始；其中已按用户确认的 AS5048A SPI 六线颜色及数据手册实现真实端口，并给出独立接线表。该台架的 H25 已通过受限带 PWM 测试，详见 [2026-09-08 扩展验收](bench-validation-20260908-haptic25-extended-cn.md)；不能据此放行本页产品板端口。

电机实物已经到货，编码器已确认为 `AS5048A + SPI`。2026-10-02 产品端口已接入 `factory_encoder_as5048a.c`：SPI1 Mode 1、16 位、2.5 MHz，TIM6 4 kHz 执行 ANGLE→DIAG→NOP，只读采样并校验奇偶、EF 和磁场诊断；原占位实现已删除。见[代码、构建与故障注入证据](../outputs/project-advance-20261002/README_CN.md)。实际线路与时序尚未验收，电角零位仍无效；编码器接入不能单独放行 arm。4 kHz 的 `250 us` 是样本新鲜度门槛，不是未经实板测量的最坏关断时间。本页产品目标不能与 NUCLEO 联调目标混用。

电机参数、资料冲突和分级首测值统一见 [GL30 到货基线](../hardware/motor-control/GL30_KV290_ARRIVAL_BASELINE_CN.md)。

补充故障验收：开机 50 ms 无新鲜 ADC 必须锁存关断；在 WAIT_BUS 阶段插入一次低于 9 V 的 ADC 帧，10 ms 稳定窗口必须重算。模拟 IWDG/WWDG 复位后，不能再次请求母线；已锁存故障且所有关断焊盘正常时允许保留通信报告，但主循环/TIM7 停摆仍不得喂狗。进入 READY 前收到的命令、排队达到 10 ms 的命令不能使能输出。这里的期限是软件检查门槛，实际响应时间须测波形。

## 1. 当前构建

```powershell
Set-Location firmware-stm32\cubemx
.\generate.ps1

cd .\GL30_AMOLED_V7\MDK-ARM
$args = @('-r', '.\GL30_AMOLED_V7.uvprojx', '-t', 'GL30_AMOLED_V7', '-j0', '-o', '.\build-ac6.log')
Start-Process G:\software\KEILV5\UV4\UV4.exe -ArgumentList $args -WindowStyle Hidden -Wait
```

`generate.ps1` 只允许一个 CubeMX Java 进程，使用无界面 `-q` 生成 MDK-ARM；不要使用 `-h`，也不要并行打开 CubeMX。当前 clean rebuild 已用 ARMCLANG 6.21 验证为 `0 Error(s), 0 Warning(s)`。

主机测试使用仓库的 `build/stm32-host` 构建目录，验证日志另存到对应日期的输出包：

```powershell
cmake -S firmware-stm32/tests -B build/stm32-host -DCMAKE_BUILD_TYPE=Debug
cmake --build build/stm32-host --config Debug
ctest --test-dir build/stm32-host -C Debug --output-on-failure
```

验收：唯一产品目标是 CubeMX 生成的 `GL30_AMOLED_V7`；活动生产路径不含 `mt6835`、旧 HAL BSP 或 `ENCODER_BENCH`；无效、超时或磁场异常的编码器样本不能通过 control-ready 门。编译和主机测试仍只属于 `BUILD_ONLY/SIM_ONLY`。

## 2. 当前可以离线完成的工作

- 阅读/测试 FOC、协议、Profile、安全监督、电流换算和故障路径。
- 画 STM32/DRV8316/三电流/电源/硬件保护公共原理图。
- 用主机故障注入验证真实 SPI1 端口的超时、奇偶校验、磁场异常和旧样本撤销；实物接入时再用逻辑分析仪检查 CS/SCK/MISO。
- 对所有命令入口做失效安全测试：故障锁存、MOE 关闭、DRV 输出关闭。
- 对已到货电机做手转检查、三对线—线电阻/电感、绕组对壳低阻排查和已知转速反电势测试；原始数据进入实验记录。
- 依据 7 极对检查反电势频率：`600 rpm`时应约 `70 Hz`。用幅值区分表中 255 rpm/V 与曲线标题 KV290，不先选结论。

禁止猜测线序或实物电平、跨过编码器门强制 PWM、把编译通过写成硬件通过。型号与协议已经确定，不再以“编码器型号未知”为阻塞理由；上电前仍须核对当前线束与 A 板连接器针序。

## 3. 已实现接口与剩余实板核对

1. 保存厂家原文、AS5048A/板卡 datasheet、线束图和 STEP 修订。
2. 唯一 AS5048A SPI 产品实现已经接入。PA4 为上电高电平 CS；PA5/PA6/PA7 为 AF5 SPI1；确认实板与这组针脚一致。
3. 整轮采样超时为 50 µs，新鲜度门槛为 250 µs；在实际中断负载、1 kΩ MISO 串阻和线束长度下测量时序，不将主机模拟时间当作实测。
4. 把实际角度、错误位、方向、零位与电角偏置写入测试表，不直接写死未经测量的“常用值”。
5. 重新跑主机测试、ARM clean build、静态搜索和代码审查。

## 4. 实板顺序

### G2：不上电

- 核对元件方向、连接器、焊接、短路、地和电源域。
- 测六路 PWM 下拉、`DRVOFF` 上拉、`HARD_FAULT_N` 上拉和 BOOT0 下拉。
- 编码器断开；电机断开；母线断开。

### G3：只上 3.3 V

- 限流电源从低限流开始，记录静态电流。
- 检查 NRST、24 MHz、SWD、IWDG、UART 和故障输出。
- 编码器保持断开的逻辑首测条件下，核对 TIM1 MOE 关闭、六路桥臂输入为低、PB9 和 nSLEEP 为低、DRV 不 arm。接上有效编码器且温度/ADC 正常后，当前候选固件将自动请求母线，不能再假定它全程保持 PB9 低；本轮未执行烧录。
- 逐路注入 SOA/B/C 上下阈值、DRV nFAULT 和 16 V 比较器，确认 BKIN 异步关断。

### G4：工厂编码器，仍不接电机

- 先用万用表/示波器确认厂家电源和逻辑电平，再连接信号。
- 从低速 SPI 开始，先验证 AS5048A 奇偶校验、错误位和 14-bit 原始角，再慢速手转并保存原始帧、角度、时间戳和参考角度。
- 验证 0/360° 连续性、方向、静止噪声、刷新率、延迟、掉线和断电恢复。
- 错误/超时/线断开必须马上撤销 control-ready；不能靠上层 UI 判断安全。
- 无电机、独立限流条件下，按 `PB9 → VM稳定 → nSLEEP → 配置/采零 → DRVOFF低` 顺序捕获波形；MOE 必须始终为 0，六个 DRV 输入必须始终低。VM 缺失时应在期限检查后锁存故障并撤销两路请求，无自动重试。
- 检查原始 nFAULT 上电上拉、共享 PB12、CSA 中点、512 样本波动和 NPOR 确认前后寄存器。只有 NPOR 的一次确认不等于可以自动清除运行故障。B 板自主再生钳位及供电隔离未验收前，不接电机进入下一步。

### G5：低压低流电机

- 先确认 7 极对；三对线—线电阻目标约 `1.53 ohm`。线电感没有仪器时先采用厂家 `330 uH` 和折相 `165 uH`，不阻塞首轮 9 V/0.2 A 测试；出现电流振荡/异常纹波、准备提高约 150 Hz 初始带宽或升流前，再用 LCR 或低压 `di/dt` 法辨识。只在机械自由、可急停条件下进行。
- 从 9 V 受限母线和 `0.2 A` 电流限值开始；确认电流极性/相序后再做电角度对齐。锁定不足时最多先升到 0.3 A，不直接跳到额定电流。
- 先开环测相序，再闭电流环；禁止同时改相序、编码器方向、PI 和力矩常数。
- 闭环按 `0.5 A → 1.0 A → 1.6 A` 逐级放行；当前 1.75 A 软件硬限和名义约 1.8 A 的外部窗口不允许测试厂家 7.4 A 峰值。外部窗口尚未实测，按器件公差粗估可能为 1.47–2.17 A，所以必须先在低电流区标定再放行 1.6 A。
- 每次只改一个参数，保留固件哈希、波形、参数和结果。

## 5. FOC 调参顺序

1. ADC 零偏：三相在无电流时的均值、峰峰值和温漂。
2. 电流比例：用已知直流电流核对 SOx 与 INA228/电流表。
3. 相序与编码器方向：正电角必须对应期望机械正方向。
4. 电角零位：多次重复对齐，统计均值和离散，不用一次值冻结。
5. 电流 PI：厂家给出的是线—线 `1.53 ohm / 330 uH`，当前 dq 首次上电初值使用相值 `0.765 ohm / 165 uH` 和约 150 Hz 带宽，即 `Kp=0.16 V/A`、`Ki=720 V/(A·s)`；从低幅值阶跃开始，记录上升、超调、稳态误差和 deadline。只有极性、ADC 时点、R/L、死区和阶跃波形闭合后，才尝试约 250 Hz 的 `0.26 / 1200`。
6. 力矩/触觉：先纯阻尼，再摩擦、惯量、卡点、端止挡；每项独立验证。
7. 回灌与热：从低速轻拨开始，确认 14.4/16 V 链，再增加工况和持续时间。

## 6. 每次实验记录

- 日期、操作者、板号、电机/编码器批次、机械版本。
- Git commit、固件哈希、编译器和构建命令。
- 母线、电流限值、转速/手动动作、环境温度和持续时间。
- 原始波形/日志，不只留截图结论。
- 通过标准、实际结果、失败模式和下一步唯一变量。

只有 G0–G7 对应证据闭合后，才能把项目从 `BUILD_ONLY/CAD_CHECKED` 提升到 `BENCH_TESTED/INTEGRATED_TESTED`。

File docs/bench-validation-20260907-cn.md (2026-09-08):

# GL30 续测验收报告：2026-09-07

> 公开归档说明：正文记录当时状态；本地 `output/`、`tmp/` 位置以代码标记，不伪装成 GitHub 可点击文件。当前结论与本次公开的原始证据包见 [2026-09-08 扩展验收](bench-validation-20260908-haptic25-extended-cn.md)。

> **历史报告：本页记录 HAPTIC8，保留原始结果，不代表当前烧录镜像。** HAPTIC9 UART 修复及 HAPTIC10 的 9–15 V 窗口调整/ALIGN 位移故障见 [HAPTIC10 历史报告](bench-validation-20260907-haptic10-cn.md)；当前 HAPTIC25 的时序修复、ALIGN / IQ / 八模式 smoke 结果见 [HAPTIC25 续测验收](bench-validation-20260907-haptic25-cn.md)。下文旧 13.2 V 门、HAPTIC8 哈希和停止时间仅适用于当时测试。

## 1. 当前结论与范围

**阶段：`ADC_CLOCK_FIXED / POWERED_ALIGN_HOLD`。不能标记“所有主要功能通过”。**

- 真实台架为 NUCLEO-G474RE + TI DRV8316REVM + GL30 KV290（7 极对）+ AS5048A SPI；当前已刷写并完整回读确认的固件为 `20260907_HAPTIC8`。
- 全部续测、代码修改和最终复核由主线程执行；本轮没有调用其他模型或 Worker，也未要求人工在旁守台。
- 不删除文件，不清理既有未提交改动，不提交 Git；原始失败、旧固件、源文件快照与新结果分目录保留。
- 电源 305 mA 限流为用户报告，未用仪表核实，不等于相电流限流。未操作电源旋钮、开关或接线。
- 当前固件的校准仍失败。无 PWM 稳定性、协议拒绝和故障自动关断通过，不能替代带开关噪声的采样、电流环及真实触觉验收。

## 2. 主要功能验收矩阵

| 功能 | 已验证 | 本轮结论 / 边界 |
| --- | --- | --- |
| C 协议、FOC 数值/安全、状态门、DRV/编码器诊断、触觉原语 | 6/6 测试程序；ASan+UBSan 同样 6/6 | PASS（主机软件；不是 6 项硬件认证） |
| TypeScript 协议/Core/Profile/模拟器 | 4 个 workspace 类型检查；21/21 测试 | PASS（软件） |
| 无硬件端到端 | Profile 2/2；5 个有效解析帧/1 个预期坏帧；3 条应用/2 条丢弃；COMM_LOST 禁止力矩；4096×6 trace→205 bins | PASS（SIM_ONLY） |
| NUCLEO 固件与烧录 | Keil 0 error/0 warning；47288 字节镜像；完整 Flash 读回 SHA256 一致 | PASS（当前 HAPTIC8） |
| ADC 时钟配置 | 同源 PLLP 40 MHz + 异步 ÷1；实机 RCC/ADC common 寄存器精确核对 | PASS（配置修正，不等于已定位模拟异常全部根因） |
| AS5048A 无输出采样 | 3 轮自检，6144/6144 有效点；各轮相邻间隔全部 250 μs | PASS（该无输出采样窗口） |
| PREPARE / 校零 / 无 PWM 稳定性 | health=63、zero=1；60.477 s 准备态；无新增故障 | PASS（只唤醒电子电路，MOE=0） |
| 命令拒绝/解析恢复 | 56 个实机用例：范围、畸形/二进制/过长输入、拆包、8 类未校准触觉拒绝、重复 STOP 等 | PASS（未允许任何出力路径） |
| 软件故障锁存与清错 | FAULTTEST→1024；STOP 保留故障；CLEAR 保留首故障快照但不恢复校准；随后 IQ/HAPTIC 仍拒绝 | PASS（软件注入，不是外部 BKIN/过压电路认证） |
| 现有控制台诊断 | 新接入 ENC_FIELD / CURRENT_DIAG；自动提供只读输入并读取真实 COM4；退出后停止状态通过 | PASS（测试工具首轮作用域错误已修正并保留失败记录） |
| 机械/电角校准 ALIGN | 本版本仅 1 次；约 0.484 s 触发 HEALTH，未完成机械位移验证 | **FAIL / HOLD** |
| 正反向 IQ 电流环 | 当前版本未通过 ALIGN；本轮只测未校准拒绝路径 | **BLOCKED，不能报通过** |
| 8 类 HAPTIC 实物效果 | 软件预设与限幅测试通过；当前版本没有获准实际出力 | **BLOCKED，不能报手感/速度环通过** |
| 产品 GL30_AMOLED_V7 | 同步修正 ADC 时钟；独立 Keil 构建 0 error/0 warning | BUILD_ONLY，未烧到 NUCLEO；factory_encoder_pending 未放行 |
| ESP32、AMOLED/LVGL、无线、HID、OTA、完整 PC 采集/应用适配 | 仓库当前仍是框架或计划，ESP32 无可烧录 ESP-IDF 应用 | **未实现/未验收，不伪造测试成功** |
| 整机机械、热、回灌、寿命及外部保护链 | 本次未取得新的整机验证证据 | HOLD；台架局部通过不放行产品 G4/G5/G7 |

软件记录：最终回归清单（`../output/bench/haptic8-20260907/final-regression/validation.json`）、C 详细日志（`../output/bench/haptic8-20260907/final-regression/host-ctest.log`）、Sanitizer 日志（`../output/bench/haptic8-20260907/final-regression/sanitizer-ctest.log`）、TS/E2E 日志（`../output/bench/haptic8-20260907/final-regression/pnpm-verify.log`）。C 日志中的大数量为断言/枚举检查计数，不包装成同等数量的独立功能用例。

## 3. 本次修正及证据链

### 3.1 首故障快照（HAPTIC7，HAPTIC8 保留）

原先部分 ALIGN 终端失败/健康门失效会使 CURRENT_TRIP 留空或丢失首故障。增加独立首故障标记，所有相关关断先冻结当前 ADC 时间、同步状态、原始值/零点以及 fault、align_stage、align_move；CLEAR 保留证据而允许下一故障事件替换，新 ALIGN/初始化清空。平均电流非有限值不能通过 ALIGN。

回归先出现 13 个失败断言，修复后诊断测试共 420 断言通过；本次普通与 Sanitizer 构建均重新运行。见 HAPTIC7 证据目录（`../output/bench/haptic7-20260907/`）。这是诊断完整性修正，不是绕过故障。

### 3.2 ADC 并发时钟勘误（HAPTIC8 及产品工程）

依据本地归档的 ST ES0430 Rev 9，June 2024（`../output/bench/haptic8-20260907/ES0430.pdf`） 第 1、3、17–18 页，适用条款是 **§2.7.11**，选用同一时钟源、ADC 预分频 ÷1 的 workaround。实机 REV_ID=0x2003 是 **Rev X**。不能把 §2.7.9 的 >1 ms 首转换条件套到持续 50 μs 周期；§2.7.10 不影响 Rev X，不据此添加 dummy rank。

| 实机寄存器 | HAPTIC7 | HAPTIC8 |
| --- | --- | --- |
| DBGMCU_IDCODE | 0x20036469 | 0x20036469 |
| RCC_PLLCFGR | 0x01005032 | 0x41015032 |
| RCC_CCIPR | 0xA0000000 | 0x50000000 |
| ADC12_CCR | 0x00030000 | 0x00000000 |
| ADC345_CCR | 0x00030000 | 0x00000000 |

修正前只读证据（`../output/bench/haptic8-20260907/clock-before/validation.json`）、修正后只读证据（`../output/bench/haptic8-20260907/clock-after/validation.json`）、适用性判断（`../output/bench/haptic8-20260907/errata-assessment.json`）。读取前已 STOP，SWD 使用 HOTPLUG 只读，不停核；没有在出力时调试停核。

台架 main.c 与 IOC 同步改为 HSI/M4/N80/PLLP8；产品 main.c 与 IOC 为 HSE/M6/N80/PLLP8。两者 ADC 实际都维持 40 MHz，采样长度与 rank 不变。**台架仍 20 kHz，产品仍原有 40 kHz PWM；全部保护阈值不变。** 产品编译通过不等于该板硬件通过，也没有用产品固件替换 NUCLEO。

配置满足勘误的规避条件，但不能由此证明它就是之前大幅三相负偏移的唯一原因；新版本 ALIGN 仍失败，根因尚未闭合。

### 3.3 控制台与分析工具

- [evm_console.ps1](../firmware-stm32/bench/NUCLEO_G474RE_FOC/evm_console.ps1) 增加 ENC_FIELD/CURRENT_DIAG 两个诊断入口，不改变出力门。
- 首故障/编码器离线分析器（`../tmp/bench/analyze_haptic_capture.py`） 与准备态分析器（`../tmp/bench/analyze_prepared_soak.py`） 从保存的 CSV/JSON 重算，不访问硬件，不覆盖既有分析。
- 修正准备态脚本对 ordered dictionary 的控制台投影问题；原 validation.json 一直完整有效，旧测试未因打印 null 重跑。
- 控制台测试首轮 Read-Host mock 使用跨脚本 `$script:` 队列导致工具错误；改为本次独立进程的明确共享队列后通过。没有为使测试通过修改生产行为或断言。首轮错误记录（`../output/bench/haptic8-20260907/hardware/console-diagnostics/failure.json`）、修正后实机证据（`../output/bench/haptic8-20260907/hardware/console-diagnostics/retry-1/validation.json`）。

## 4. 真实硬件结果，不将失败解释为成功

### 4.1 HAPTIC4–8 阶段记录

| 版本 | 真实结果 | 证据 |
| --- | --- | --- |
| HAPTIC4 | HOTPLUG 下载首试失败，后来 under-reset 下载/完整回读通过；3 自检、256 次磁场读取通过，不代表校准通过 | 硬件目录（`../output/bench/haptic4-20260907/hardware/`） |
| HAPTIC5 | 单次 ALIGN 触发 CURRENT=16；捕获 470 个编码器点；自动停止 | 记录（`../output/bench/haptic5-20260907/hardware/align-capture/validation.json`） |
| HAPTIC6 | 200 ms 初始保持单独通过但未校准；完整 ALIGN 触发 ALIGN=8、位移不足，旧首故障快照留空暴露诊断缺陷 | 短保持（`../output/bench/haptic6-20260907/hardware/current-trip-probe/validation.json`）、完整尝试（`../output/bench/haptic6-20260907/hardware/align-capture/validation.json`） |
| HAPTIC7 | 首故障诊断修复后单次 ALIGN 触发 CURRENT=16；三相重算总和约 -0.953 A，提示测量链异常，不能靠滤波忽略 | 原始结果（`../output/bench/haptic7-20260907/hardware/align-capture/validation.json`）、重算（`../output/bench/haptic7-20260907/hardware/align-capture/analysis.json`） |
| HAPTIC8 | 时钟修正、无输出采样通过；单次 ALIGN 触发 HEALTH=1；随后 60 s 无 PWM 准备态和命令回归通过 | ALIGN（`../output/bench/haptic8-20260907/hardware/align-capture/validation.json`）、准备态（`../output/bench/haptic8-20260907/hardware/prepared-soak/validation.json`）、56 用例（`../output/bench/haptic8-20260907/hardware/off-command-regression/validation.json`） |

### 4.2 HAPTIC8 的单次 ALIGN 首故障

2026-09-07 16:19:38 UTC 开始该次会话；只发一次 ALIGN，没有失败后反复带电尝试。

```text
CURRENT_TRIP sample=3759799 us=187990019
raw=2018,1790,1799,1244
zero_mc=1871500,1873269,1873347
sync=1 bad=0 outputs=3 fault=1 align_stage=0 align_move_mrad=-71
```

按固件既有 3.3 V/4095、CSA 0.6 V/A、VM 分压 75 kΩ/6.04 kΩ换算：Ia=+0.19676 A、Ib=-0.11184 A、Ic=-0.09986 A，总和=-0.01493 A；VM=**13.45064 V**。该 VM 超过既有 13.2 V 健康门；故障时仍在初始静态场阶段，速度观测约 -0.282 rad/s。`outputs=3` 只表示故障关断前 MOE=1、nFAULT=1；该字段不含 DRVOFF。

故障证据说明软件门正确关断，**不证明电源真实过压，也不证明 ADC/模拟链已可靠**。尚不能区分真实母线瞬态、模拟地/VREF 干扰或采样异常。1935 个编码器点均有效、相邻间隔 250 μs，不是独立的轴运动测量。原始串口（`../output/bench/haptic8-20260907/hardware/align-capture/serial.log`）、CSV（`../output/bench/haptic8-20260907/hardware/align-capture/samples.csv`）、可复现重算（`../output/bench/haptic8-20260907/hardware/align-capture/analysis.json`）。

### 4.3 无输出采样与 60 秒准备态

- 3 轮无输出采样合计 6144/6144 点，各轮全部相邻 dt=250 μs。`self_max=2501`、历史 `isr_max=3381`，低于未改变的 3600 cycles 预算；`window_min=974`；deadline/adc_bad/enc_err/uart_err/self_fail/iwdg_reset 为 0。无输出数据（`../output/bench/haptic8-20260907/hardware/off-captures/analysis.json`）。
- 60.477 s 准备态中，主机读取 125 个 CURRENT_LIVE、记录 126 个 PREPARED STATUS；所有 STATUS 的 MOE=0，准备态 health=63/zero=1/fault=0。两端计数差 ADC=1,200,775、有效编码器=240,155；错误计数无新增。
- 125 个稀疏主机快照的 VM 推算范围 **12.01259–12.15315 V**；三相零电流 RMS 约 **3.16/3.09/2.62 mA**，最大绝对偏差约 11.38 mA。这不是连续 20 kHz 原始波形，也不是仪表实测精度。
- 16 次 ENC_FIELD 协议和诊断均有效；AGC 全为 255，magnitude 4505–4515。仅记录观测值，不据此宣称磁铁损坏、磁场裕量合格或编码器是全部根因。
- 准备态最终 STOP 并释放 COM4。离线分析（`../output/bench/haptic8-20260907/hardware/prepared-soak/analysis.json`）。

### 4.4 无出力拒绝路径与最终状态

2026-09-07 16:42:55 UTC 开始的 56 用例中，所有 IQ/HAPTIC 请求只在已断言 OFF/FAULT、未校准状态发送并验证拒绝；没有发送 ALIGN、BREAKTEST 或 DRV_TRACE。范围测试包含正负边界、超长整数、错误格式、二进制字节、过长行与后续恢复；软件注入验证 CLEAR 不恢复出力资格。完整串口日志（`../output/bench/haptic8-20260907/hardware/off-command-regression/serial.log`）。

控制台集成于 2026-09-07 16:52:50 UTC 完成；随后于 **2026-09-07 17:18:04 UTC** 独立执行 STOP / STATUS / CURRENT_DIAG / STOP / STATUS 并再次关闭串口，最终停止证据（`../output/bench/haptic8-20260907/hardware/final-stop/validation.json`）通过。最终真实 STATUS：`mode=0 fault=0 MOE=0 DRVOFF=1 zero=0 calibrated=0`，错误计数无新增；串口关闭，无后台运动任务。CURRENT_TRIP 此时保留的是上述测试故意注入的 **1024**，不是新电流/母线故障；HAPTIC8 真实 HEALTH 首故障已单独归档，不能混淆。软件 STOP 不代表外部电源已断开。

## 5. 构建身份与复核

| 镜像 | 字节数 | SHA256 | 使用边界 |
| --- | --- | --- | --- |
| NUCLEO HAPTIC8 | 47288 | `A6C5D89C8D6FA9FCC0F7CD5F8DE5057BC7A1D400B89BE0D2D4BF9766A2375665` | 已烧录，完整读回一致 |
| 产品 ADC_PLLP40 | 31320 | `B58B68085349C31FF57B13B902E2460A88FB8B5E20EA936C150C3E922644CEEF` | 只构建，未刷硬件 |

台架源码清单（`../output/bench/haptic8-20260907/build-validation.json`）、烧录/完整回读（`../output/bench/haptic8-20260907/hardware/flash-validation.json`）、产品源码与构建清单（`../output/bench/haptic8-20260907/product-clock/build-validation.json`）。已核对的安全参数维持：相电流 0.35 A、ALIGN 0.20 A、矢量 0.30 V、母线 9.0–13.2 V、速度 8 rad/s、IQ/HAPTIC ±100 mA、失联 100 ms、ALIGN 超时 6 s、ISR 3600 cycles。B1 持续按住门早已移除，本轮没有恢复；也未继续放宽上述保护。

最终独立审计（`../output/bench/haptic8-20260907/final-audit.json`）逐项重算台架 19 项和产品 317 项构建清单记录、两套镜像及 Flash 回读的 SHA256，核对控制台源码身份、main/IOC 变更边界、原始故障换算、测试日志与本文链接。清单项有跨工程重复，不表示 336 个独立模块。该审计不访问硬件，也不把 ALIGN 的 HOLD 改成通过。

最终停止检查距控制台集成的两端计数差为 ADC +30,267,206、有效编码器 +6,053,442；错误计数无新增。这里只是两端累计计数核对，不是这段时间的连续原始波形。停止后的 zero=0、CURRENT_LIVE valid=0；未校零的电流字段不作真实相电流测量。

## 6. 继续推进所需的真实条件

1. 先获取可区分真实 VM 瞬态与 ADC/模拟链异常的证据，例如可信 VM、VSENVM、CSA/VREF 波形或更密集的故障前原始采样；不能凭单帧推断直接改滤波、提高电压/电流门。
2. 出力采样问题闭合后，才做有边界且记录完整的 ALIGN；成功后按顺序验证短正反 IQ，再验证 8 类触觉。短时启动/完成、软件自检和拒绝路径都不能代替这一步。
3. 产品仍保留 factory_encoder_pending；ESP32 传输/界面和整机功能需要真实实现与各自构建、E2E 及硬件证据。不能靠台架通过跳过 [硬件闸门](hardware-gates.md)。

以上是实际完成与真实阻塞，不把未实现、未测或已失败的项目计为通过。

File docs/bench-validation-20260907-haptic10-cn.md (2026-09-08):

# GL30 HAPTIC10 续测验收：母线窗口调整与 ALIGN 位移故障

> 公开归档说明：正文记录当时状态；本地 `output/`、`tmp/` 位置以代码标记，不伪装成 GitHub 可点击文件。当前结论与本次公开的原始证据包见 [2026-09-08 扩展验收](bench-validation-20260908-haptic25-extended-cn.md)。

> **历史报告：本页是 HAPTIC10 当时的失败与停机证据，正文不改写为成功。** 当前 HAPTIC25 已通过受限 ALIGN、短时双向 IQ 和八模式硬件 smoke，见 [HAPTIC25 续测验收](bench-validation-20260907-haptic25-cn.md)。下文“当前”只指 HAPTIC10 测试时刻。

日期：**2026-09-07 UTC**。当前状态：**`VM_WINDOW_UPDATED / ALIGN_TRAVEL_HOLD`**。本页接续 [HAPTIC8 历史报告](bench-validation-20260907-cn.md)，不是整机放行报告。

## 1. 当前结论

- 当前烧录的是 **`FW=20260907_HAPTIC10`**，NUCLEO-G474RE + TI DRV8316REVM + AS5048A 台架；不是产品 CET6 镜像。
- 已按用户授权把台架母线健康窗口 **9.0–13.2 V → 9.0–15.0 V（含端点）**。没有关闭电压有限值检查，也没有增加相电流、ALIGN 电流、输出矢量电压、速度、失联或 ISR 限额。
- 软件回归、无出力命令、UART 耐久/全双工拥塞/异常字节恢复和 60 秒无 PWM 准备态已通过。
- **HAPTIC10 只发过一次 ALIGN**。约 4.5 秒后因机械最终净位移不足报 `fault=8` 并关断；不再是旧的 13.2 V 健康门提前关断。**真实 IQ 与 8 类 HAPTIC 出力仍未通过，不伪装成全功能通过。**
- 所有工作由主线程完成，未调用其他模型/子代理；不删除文件、不提交 Git、不清理其他未提交改动；没有要求人工守台，没有操作外部电源开关或调大限流。
- 电源 **305 mA** 只是用户报告，未以仪表或电源接口核实；它不是相电流限额。

## 2. 变更、构建与镜像身份

生产修改限于台架 `bench_app.c`：新增 `VM_MIN_V=9.0f` / `VM_MAX_V=15.0f`，在 `health`、`PREPARE`、`DRV_LIVE`、`DRV_TRACE`、`Bench_DriverTraceSafe` 五个检查处统一使用，更新三条拒绝文本和 HAPTIC10 BOOT 标记。相对 HAPTIC9 的生产最小 diff（`../output/bench/haptic10-20260907/production-voltage.diff`）已保存。

| 保留项 | 当前值 |
| --- | --- |
| 相电流采样关断阈值 | 0.35 A |
| ALIGN 静态 d 轴目标 | 0.20 A |
| 电压矢量上限 | 0.30 V；不是直流母线电压 |
| IQ / HAPTIC 限幅 | ±100 mA |
| 速度 / 主机续租 | 8 rad/s / 100 ms |
| ISR 时间预算 | 3600 cycles |
| PWM / 编码器 | 20 kHz / 4 kHz |
| 校准成功条件 | 单向电角一圈后，机械净位移绝对值严格处于 2π/7 的 0.8–1.2 倍范围内 |

TI 官方 DRV8316 Rev.B 手册第 6 页列出 VM 推荐工作范围 4.5–35 V、绝对最大 40 V；本次没有按芯片极限放开窗口，也没有把芯片额定值当作整板、接线或回灌验收。官方原文已归档在本地 PDF（`../output/bench/haptic8-other-20260907/ratings/drv8316.pdf`），本轮也重新读取了 TI 官方 PDF。**9–15 V 是软件接受边界，实物未做全区间扫压；旧 13.451 V 采样的物理成因仍未由仪表闭合。**

| 镜像项 | 实际结果 |
| --- | --- |
| Keil | 0 error / 0 warning；Code 41876、RO 5312、RW 28、ZI 28060 |
| 文件 | `NUCLEO_G474RE_FOC_HAPTIC10.bin`，47224 字节 |
| SHA256 | `87ED9CB2FB54B44BF100FE6082F593EE6B5EDCEC655A42C092BBD0B5D25586D7` |
| 烧录 | 实际 BOOT 收到 HAPTIC10；编程校验及完整可执行镜像区读回一致 |
| 最终复核 | 再次读回相同 47224 字节并核对相同 SHA256；不是声称读取整颗 512 KB Flash |

证据：构建及 19 项源码哈希（`../output/bench/haptic10-20260907/build-validation.json`）、烧录记录（`../output/bench/haptic10-20260907/hardware/flash-validation.json`）、最终读回/停机（`../output/bench/haptic10-20260907/hardware/final-stop/validation.json`）。最终交付审计另列在审计 JSON（`../output/bench/haptic10-20260907/delivery-audit-final/validation.json`）。

## 3. 软件：先红后绿，最后独立复跑

母线新增测试覆盖 `8.999 / 9 / 12 / 13.450639 / 14.999 / 15 / 15.001 / NaN / +Inf / -Inf`；检查五个入口行为一致、接受电压不会自动开 PWM、越界不会配置/唤醒驱动。

1. 对旧 HAPTIC9 运行新期望：build=0，测试退出码 8，**15/1587 断言失败**，证明旧实现不满足新窗口。红测结果（`../output/bench/haptic10-20260907/voltage-red-result.json`）、红测日志（`../output/bench/haptic10-20260907/voltage-red-test.log`）。
2. 改生产实现后第一次回归仍失败：仅 BOOT 测试还期待 HAPTIC9，旧失败原样保留。更新为真实 HAPTIC10 标记后全部通过；没有弱化电压、校准或出力断言。首次失败（`../output/bench/haptic10-20260907/final-regression/validation.json`）、修正后通过（`../output/bench/haptic10-20260907/final-regression-2/validation.json`）。
3. 硬件测试结束后，于 **21:13 UTC** 再独立执行 build、CTest、Sanitizer、类型检查及 SIM_ONLY E2E，全部通过。最终复跑结果（`../output/bench/haptic10-20260907/delivery-regression/validation.json`）。

| 项目 | 已验证结果 | 证据边界 |
| --- | --- | --- |
| C 回归 | 6/6 测试程序 | 协议/FOC/状态门/驱动及应用诊断/触觉行为；不是 6 项实物功能验收 |
| ASan + UBSan | 同为 6/6 | 软件内存与未定义行为检查 |
| 应用 / 硬件诊断 | 1587 / 4937 次断言 | 包含正常、故障、时间回绕和拒绝路径；断言数不是独立硬件试验数 |
| TypeScript | 21/21；4 个 workspace 类型检查 | 协议、core、profile、模拟器 |
| SIM_ONLY E2E | Profile 2/2；5 parsed + 1 预期坏帧；3 applied / 2 dropped；COMM_LOST 禁止扭矩；4096×6 → 205 bins | 没有真实 ESP32、屏幕、无线或 PC 外设链路 |

本轮没有修改 fake `main.h`；新增行为测试与实际固件对应。测试专用脚本/历史日志保留，不用替换测试结果掩盖失败。

## 4. 唯一一次带 PWM 的 ALIGN

完整采集目录（`../output/bench/haptic10-20260907/hardware/align-capture/`）包括 validation、串口记录、24 条运行态 STATUS、2048 点冻结编码器缓冲及重算 analysis。

- PREPARE 和 12 次校零漂移检查通过。约 **20:45:53.7–20:45:58.2 UTC** 执行一次 ALIGN，没有自动重试。
- 1 秒静态段（前 0.4 秒渐升）后进入 3 秒平滑旋转场，再保持 0.5 秒。旋转段采用约 **0.266 V** 的已测固定 Vd。
- 24 条运行态 STATUS 的 `health=63`，未新增 HEALTH/CURRENT/DRV/ADC/ENC/deadline/UART 故障；`self_max=2534`、`isr_max=3407`，均低于 3600。
- 旋转起点约 **2.140 rad**，中途最低约 **1.678 rad**，随后回到约 **2.141 rad**。电场走完一电周期，转子的最终净位移在首故障记录中截断为 **0 mrad**。
- 预期机械净位移绝对值 **2π/7 ≈ 0.897598 rad**，接受开区间约 **(0.718078, 1.077117) rad**。实际不满足，固件正确锁存 **ALIGN fault=8** 并关断；不把拒绝成功当作校准成功。

冻结首故障：

```text
CURRENT_TRIP sample=642185 us=32109319
raw=2019,1786,1802,1119 zero_mc=1870734,1872447,1872591
sync=1 bad=0 outputs=3 fault=8 align_stage=1 align_move_mrad=0
```

按固件比例重算：`Ia=+0.199136 A`、`Ib=-0.116107 A`、`Ic=-0.094811 A`，相和 `-0.011782 A`，VM `12.099087 V`。这些是 ADC 推算，不是独立电流探头/电压表读数。`CURRENT_TRIP.outputs` 仅 bit0=事前 MOE、bit1=事前 nFAULT，**不含 DRVOFF**。

2048/2048 冻结编码器样本有效，覆盖故障前约 **0.512 秒**，不是完整 4.5 秒波形；末窗口码值 5580–5588，软件重放未超过 8 rad/s。主机完整轨迹依据稀疏 STATUS，不能把它当作独立轴角或高带宽三相波形。

**根因仍未证明。** 当前证据可确认“在现有限额下没有完成预期机械净位移”，但不能单凭它区分机械跟随/齿槽或装配阻力、磁场/位置测量等原因。正反方向校准主机测试通过，未找到可用本次实物证据证明的算法缺陷；不改通过阈值、不写入假零位、不增加电流/电压、不盲目重复 ALIGN。

## 5. HAPTIC10 其他实机测试

| 项目 | 结果与关键数据 | 证据 |
| --- | --- | --- |
| 编码器磁场只读 | 64 次：mask=15、valid=7，诊断高位 0x100；angle 5764–5769，AGC=255，magnitude 4510–4522；CLEAR 前后首故障保留 | field validation（`../output/bench/haptic10-20260907/hardware/encoder-field-after-align-3/validation.json`） |
| 无出力命令/故障恢复 | 56 cases；IQ 和 8 类 HAPTIC 未校准拒绝、格式/范围、分片/二进制/超长行、STOP 幂等、FAULTTEST=1024、CLEAR 不恢复校准、SELFTEST | command validation（`../output/bench/haptic10-20260907/hardware/off-command-regression-2/validation.json`） |
| UART 耐久 | 4096 有序回显；95 字节合法边界；流量下 SELFTEST；200 STATUS 拥塞及恢复；120 秒/727 轮 soak；742 STATUS、728 CURRENT_LIVE；3 次重连不重新上电 | endurance validation（`../output/bench/haptic10-20260907/hardware/io-endurance/validation.json`） |
| 全双工拥塞 | 400 请求 → 204 个完整回复 + 196 个由计数核对的整帧丢弃；无半帧/混帧，幸存回显唯一有序，随后恢复 | duplex validation（`../output/bench/haptic10-20260907/hardware/uart-duplex-malformed/validation.json`） |
| 非法输入 | 159 种非法二进制字节不拼成 SELFTEST；96/255/256/257/4096 字节超长行拒绝并恢复；同轮共 258 条检查记录（含重复状态检查） | 同上；**不含 UART BREAK** |
| PREPARE 无 PWM soak | **60.154 秒**，125 条准备态 STATUS、124 次 CURRENT_LIVE、16 次 ENC_FIELD；全部 MOE=0，准备态 fault=0/health=63/zero=1 | soak validation（`../output/bench/haptic10-20260907/hardware/prepared-soak/validation.json`）、离线分析（`../output/bench/haptic10-20260907/hardware/prepared-soak/analysis.json`） |

无 PWM soak 中，ADC 推算 VM **12.0234–12.1531 V**；三相电流 RMS 约 **3.392/3.333/2.775 mA**。准备态期间 ADC 增加 1194141、编码器有效回复增加 238829，ENC/ADC/deadline/UART/self_fail/IWDG 计数增量为零。宿主稀疏快照不是完整采样波形，也不证明带 PWM 模拟完整性或磁场余量。

AS5048A 四帧 SPI pipeline 只有三份有效数据，所以 `mask=15, valid=7` 是本协议的正确结果。AGC=255 是读数，不独立等同“磁铁坏”或“磁场完全通过”。

UART endurance 的 batch16 延迟中位数 **81.8864 ms** 是 16 条命令组成的批次耗时，不是单条 RTT。没有遇到真实时间戳回绕，**实物时间戳回绕未验收**。最终 `uart_err=390` 来自两个已记录的故意拥塞阶段（194+196），不能写成总计数为零；恢复及后续 soak 无新增。

## 6. HAPTIC9 UART 修复与仍开放的 BREAK 问题

HAPTIC10 保留 HAPTIC9 的两项修复：RX 损坏时清队列并丢弃至下一换行，避免残片拼成合法命令；PING 回复按完整帧原子入队，避免拥塞时半条回复。有效红测为 uart-red-2-test.log（`../output/bench/haptic8-other-20260907/uart-red-2-test.log`） 的 **14/459 断言失败**；HAPTIC9 最终 1501 次应用断言通过。更早含 fixture 问题的 18/459 不是可靠红测。

早期同步写大 burst 的宿主工具有接收缓冲丢帧混杂，不能据此独立归因固件。改用全双工后，HAPTIC9 拥塞子项通过，但随后 UART BREAK 出现 BOOT，**整轮仍为 FAIL**，旧完整失败记录（`../output/bench/haptic9-20260907/hardware/uart-fault-recovery-duplex/validation.json`）没有改成 PASS。

烧 HAPTIC10 前，以 SWD HOTPLUG 只读 RAM 中缓存的 RCC_CSR：**2026-09-07 20:38:21 UTC，0x04000003，仅 PINRSTF=1**，BOR/SFT/IWDG/WWDG/LPWR/OBL 标志均为零；没有 halt、复位或写寄存器。它只证明缓存的引脚复位标志，**不能证明谁拉了复位脚，更不能直接归因某个 ST-LINK 功能**。只读取证（`../output/bench/haptic9-20260907/hardware/reset-cause-readonly/validation.json`）。

HAPTIC10 没有再次发送 UART BREAK；新异常字节测试使用单独 runner/结果名，明确排除此项。旧 USB-only watchdog / BREAKTEST 需要 EVM 断开，本次没有运行，不能计为通过。

## 7. 工具失败与证据完整性

以下失败均保留原目录，成功重试另建目录，没有降低生产通过条件：

- HAPTIC10 第一轮软件绿测：唯一失败为仍期待旧 BOOT 标记；修正测试身份后复跑通过。
- `encoder-field-after-align`：在 FAULT 状态请求只允许 OFF 的 ENC_DIAG，被固件正确拒绝。第二次误把 valid mask 期望成 15；修正为真实四帧 pipeline 的 7，第三次通过。失败/不完整记录以及两份 runner 快照保留。
- `off-command-regression`：先前诊断退出后仍处于 ALIGN fault=8，入口 OFF 断言拒绝；读取/保留真实故障并正确 CLEAR 后，新目录 `off-command-regression-2` 的 56 项通过。
- UART 新 runner 曾遇 Python 字符串编译的 BOM 工具问题；UTF-8 修正及静态检查后才运行实机。旧 BREAK 失败脚本与结果没有被替换。
- 后续 OFF 命令回归有意注入 fault=1024，因此当前 RAM 的 CURRENT_TRIP 可能对应该注入；**它不是又一次真实 ALIGN/过流故障**。真实 fault=8 已在唯一 ALIGN 目录冻结保存。

旧文档快照、HAPTIC9 生产源码快照、红测/失败日志和当前镜像均保留。当前工作区原有未提交内容未清理，也未删除文件。

## 8. 最终停止状态与未通过项

**最后实机验证：2026-09-07 21:08:48.739 UTC（美东 17:08:48.739）。**

- 串口：`mode=0 fault=0 calibrated=0 zero=0 moe=0 off=1`；最后 STOP 已应答，COM4 关闭。
- SWD 只读：`MOE=0`、`CCER=0`、`ChannelEnables=0`、`DRVOFF=1`、六路 PWM 输入及输出锁存均低；**nSLEEP=1**，电子电路仍醒着，不能写成物理断电或全板休眠。
- 全部 47224 字节可执行镜像区再次读回 SHA 一致；读取期间 ADC 前进，`adc_bad=enc_err=deadline=self_fail=iwdg_reset=0`，`rate=1`。
- STOP 使校零无效，`zero=0` 后 STATUS 中安培级相电流字段不能当作真实相电流；应使用准备态有效校零或冻结故障数据。

| 尚未通过 | 真实限制 |
| --- | --- |
| ALIGN 机械/电角校准 | 这一次确实失败，原因未闭合 |
| 真实 IQ 闭环、8 类 HAPTIC | 校准未通过，仅拒绝路径与软件行为通过；没有运行成功校准后的实物出力测试 |
| UART BREAK 恢复 | HAPTIC9 曾复位；HAPTIC10 未重试，不计为通过 |
| 实物时间戳回绕、USB-only watchdog / BREAKTEST | 本轮未覆盖；主机回绕测试不替代实物证据 |
| CET6 产品端口、ESP32/AMOLED、无线/HID/OTA、真实 PC/设备整链 | 不是本次台架验收；原 HAPTIC8 功能矩阵与实现边界仍保留，不虚构整机通过 |
| 热、回灌、动态电气波形、全母线窗口、机械手感 | 没有本轮独立仪表或完整实物验收证据 |

后续应先获得能区分机械跟随与位置测量问题的证据，再决定针对性修改；不能只通过放宽校准成功条件来继续出力。**本轮结论是“电压窗口已调整并实际续测，多项回归通过；真实校准仍失败”，不是“所有主要功能已通过”。**

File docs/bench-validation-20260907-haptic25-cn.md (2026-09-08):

# GL30 HAPTIC25 续测验收：时序修复、双向电流阶梯与八模式 smoke

> 公开归档说明：正文记录当时状态；本地 `output/`、`tmp/` 位置以代码标记，不伪装成 GitHub 可点击文件。当前结论与本次公开的原始证据包见 [2026-09-08 扩展验收](bench-validation-20260908-haptic25-extended-cn.md)。

> **阶段：`BOUNDED_BENCH_SMOKE_PASS`，不是整机或全功能放行。**
> H25 实机测试主要发生于 **2026-09-08 03:08–03:32 UTC（纽约 2026-09-07 晚）**；版本标记/目录沿用 `20260907`。本页接续 [HAPTIC10 历史报告](bench-validation-20260907-haptic10-cn.md)，历史失败没有改写成通过。

机器可读最终验收：final-acceptance.json（`../output/bench/haptic25-20260907/final-acceptance.json`）。它逐项断言源码/快照/镜像一致、回归结果、原始采样、旧失败保留和最终关断，而不是仅汇总 PASS 字符串。

## 1. 本次结论

- 板上为 **`FW=20260907_HAPTIC25`**，硬件是 NUCLEO-G474RE + TI DRV8316REVM + GL30 / AS5048A；不是产品 CET6 镜像。
- **三次真实 ALIGN 成功**；双向 `IQ ±10/±25/±50/±100 mA` 各 20 ms、八种 `HAPTIC 0..7` 各 250 ms 的受限 smoke 通过。旧 H19 失败的 `IQ -100 20` 已在 H25 通过。
- **58 项关断命令回归、60.264 s 无 PWM 准备态、21 组冻结采样独立审计通过。** 本轮 H25 实机输出测试没有新增 `deadline/adc_bad/enc_err/uart_err`；最后均为 0。
- H25 相对 H24 的解决办法是**把机械 observer 计算移出 ADC 实时路径**，不是提高电流/电压或放宽 ISR / PWM 窗口门。本轮没有改变外部电源限流、开关或接线，没有调用其他模型/Worker，没有删除文件或提交 Git。
- 用户报告的电源限流约 **300–305 mA** 未经仪表核实。H25 在外部设定未改的条件下通过；现有故障记录不支持“先加大电源电流才能解决此次失败”。没有实测输入电流/功率，不能把口述“约 3.6 W”当作供电裕量或相电流验收。

**尚未通过：** 完整手感/力矩计量、最大指令时长、长期温升、回灌、外部 nFAULT 整链、产品 CET6 编码器端口、ESP32/AMOLED/无线整机。不得将本页 smoke 泛化成这些项目完成。

## 2. 镜像身份与最终输出状态

| 项目 | 已核对值 |
| --- | --- |
| 固件 | `20260907_HAPTIC25` |
| BIN 长度 | 60136 bytes |
| BIN SHA-256 | `B98161DB5EDAE02EBCE29F0F645405C2DA73CC1B99387A67D55181E98964DFB7` |
| MAP SHA-256 | `88EBE85A86C84718A124E51E811C845BEC27F2B4AE431EBD306BD6083206D8E8` |
| AXF SHA-256 | `D9249145CE67C9D26D178752CA534B398451FABCCCF913BC5B113AF4374C3F7A` |
| 源码与快照 | 38 个文件哈希一致；AXF 再导 BIN 一致 |
| Keil | 0 Error / 0 Warning |
| 最终读回 | HOTPLUG 整个 60136-byte 镜像区 SHA-256 与 BIN 一致 |
| 最终状态 | `mode=0 fault=0 MOE=0 DRVOFF=1 zero=0 calibrated=0` |
| SWD 引脚/寄存器 | 通道使能=0、六路 PWM 输入/输出锁存均低、nSLEEP=1 |

证据：artifact-validation（`../output/bench/haptic25-20260907/artifact-validation.json`）、build-validation（`../output/bench/haptic25-20260907/build-validation.json`）、final-off-2（`../output/bench/haptic25-20260907/hardware/final-off-2/flash-validation.json`）。最后关断验证记录始于 **2026-09-08 03:31:56.504 UTC**，脚本退出码 0 并关闭 COM4；没有物理切断外部电源。

STOP 会让零点失效，随后 STATUS 中约 2.9 A 的 `ia_ma/ib_ma/ic_ma` 是**未经有效零偏扣除的读数，不能解释为真实相电流**。`iq_ma/id_ma` 也可能保留末次计算值；最终关断以状态门、MOE、通道和引脚证据判断，不拿这些旧值继续调参。

## 3. 软件与无出力验证

| 验证 | 结果 | 证据 |
| --- | --- | --- |
| host C 回归 | 7/7 | host-ctest（`../output/bench/haptic25-20260907/delivery-regression-2/host-ctest.log`） |
| sanitizer 回归 | 7/7 | sanitizer-ctest（`../output/bench/haptic25-20260907/delivery-regression-2/sanitizer-ctest.log`） |
| Release + LTO host | 7/7 | LTO 复跑（`../output/bench/haptic25-20260907/host-lto-test-2.log`） |
| `pnpm verify` | 4 个 workspace 类型检查、21/21 TS、SIM_ONLY E2E 通过 | pnpm 日志（`../output/bench/haptic25-20260907/delivery-regression-2/pnpm-verify.log`） |
| CORDIC 板上启动自检 | 65537 点、0 失败；max=225 cycles；最大误差=1907 ppb、norm=3993 ppb | soak 串口（`../output/bench/haptic25-20260907/hardware/prepared-soak/serial.log`） |
| PREPARED 无 PWM soak | 60264 ms；采样总计 1207832、冻结末 512 点；未触发 idle outlier | soak（`../output/bench/haptic25-20260907/hardware/prepared-soak/validation.json`）、原始读取（`../output/bench/haptic25-20260907/hardware/prepared-soak/current-history/validation.json`） |
| 关断命令回归 | 58/58；STOP 幂等、非法行/范围、未校准拒绝、故障锁存、CLEAR、无出力 SELFTEST | off-command-regression-3（`../output/bench/haptic25-20260907/hardware/off-command-regression-3/validation.json`） |

软件回归最新一次在 2026-09-08 03:46 UTC 重新执行；没有通过模拟器结果宣称屏幕、无线或产品硬件通过。sanitizer / host 的外设 fixture 仍是模拟外设，不能替代板上时序证据。

关断回归在 `MOE=0 / zero=0 / calibrated=0` 下执行 `FAULTTEST`，故意注入 **1024**；验证命令拒绝和 STOP 保留锁存，随后 CLEAR 只清该软件注入，**不恢复校准且保留首故障快照**。最终活动 fault=0；残留 snapshot 的 fault=1024 不是新的电机故障，也不是外部 nFAULT / BKIN 整链认证。没有执行 UART BREAK、需拆 EVM 的 BREAKTEST 或 USB-only 看门狗实验。

## 4. ALIGN、IQ 和触觉实机结果

### 4.1 三次 ALIGN

| 测试会话 | 事件 | ALIGN 结束 STATUS 净位移 | 后续 |
| --- | --- | --- | --- |
| `align-capture` | `OK ALIGNED_RAM_ONLY` | -901 mrad | ±10 mA 与八模式通过 |
| `current-ladder` | 同上 | -857 mrad | +25 mA 通过；下一个指令发送前资格门暂停 |
| `current-ladder-2` | 同上 | -923 mrad | 六项 ±25/50/100 mA 全通过 |

三次均保留真实电流资格、机械净位移门与 RAM-only 方向/零位，没有伪造校准。ALIGN 约 4.5 s、ADC 总计 90001 点；原始 ADC ring 仅保存末 512 点，**不是全段模拟波形**。主 smoke 会话静态最后 100 ms 重算平均 Id 约 0.331778 A，Vd 约 0.380004 V。

### 4.2 六项电流阶梯

每条指令 20 ms，ADC 保留全部 401 个点（首末时间跨度 20000 μs，包含终止边界样本）。下面“独立近似 Iq”由原始 ADC、现有 CSA 矩阵和最近的前向编码器采样角度重建，取可重建样本后半段均值。

| 指令 | ADC 点数 | 串口末帧 Iq / mA | 独立近似 Iq / mA | 原始三相绝对峰值 / A | 结果 |
| --- | ---: | ---: | ---: | ---: | --- |
| `IQ 25 20` | 401 | 23 | 23.09 | 0.037250 | 通过 |
| `IQ -25 20` | 401 | -29 | -24.25 | 0.036620 | 通过 |
| `IQ 50 20` | 401 | 45 | 48.45 | 0.060883 | 通过 |
| `IQ -50 20` | 401 | -49 | -49.49 | 0.058110 | 通过 |
| `IQ 100 20` | 401 | 93 | 95.27 | 0.113264 | 通过 |
| `IQ -100 20` | 401 | -90 | -93.07 | 0.111034 | 通过 |

证据：current-ladder-2（`../output/bench/haptic25-20260907/hardware/current-ladder-2/validation.json`）、独立原始审计（`../output/bench/haptic25-20260907/independent-audit.json`）。末帧不是均值；近似重建不是 bit-exact ISR observer 回放，也不是电流跟踪精度或力矩认证，不按本表额外扩大电流上限。

首次阶梯的失败记录原样保留（`../output/bench/haptic25-20260907/hardware/current-ladder/validation.json`）：+25 mA 已完成，下一个 -25 mA **未发送**，因为一个零输出 STATUS 的速度为 1507 mrad/s，超过原 1500 mrad/s 启动门。重试仅改测试调度：零输出等待最多 3 s，100 ms 采样，要求 5 次连续健康且角度跨度≤10 mrad。没有放宽速度门，没有在等待期间给电或续租；调度离线验证（`../output/bench/haptic25-20260907/settling-script-test.log`）确认超门/故障拒绝。

### 4.3 八种触觉

`HAPTIC 0..7 250` 分别覆盖自由、阻尼、档位、弹簧、限位、摩擦、惯性、速度，全部达到正常定时终止；每项 ADC 总计 5001 点，保留末 512 点。另有 `IQ ±10 20` 各 401 点通过。

证据：align-capture（`../output/bench/haptic25-20260907/hardware/align-capture/validation.json`）。**这是 `TIMED_HARDWARE_SMOKE_PASS_NOT_TACTILE_METROLOGY`**：证明八个入口在实际受限控制链上可运行并退出。自由/阻尼/弹簧等在无人工扰动、接近中心时可能只有很小电流，因此不能证明全角度效果、清晰度、力矩线性或主观手感。

## 5. 为何修时序，而不是再加电流

| 历史版本 | 保留的事实 | 对本轮的含义 |
| --- | --- | --- |
| H10 | 9–15 V 窗口调整后 ALIGN 最终净位移不足，fault=8 | 历史结论，不是 H25 当前状态 |
| H19 | ALIGN 与八模式通过；-100 mA 时只有 2 个 ADC 点即 fault=32，PWM 窗口 reason=2、CNT=267 | 原始相电流峰值仅 0.005407 A，采样 VM≈12.1099 V；本次可见故障是窗口，不是相电流不够 |
| H20 / H21 | H20 再次 ALIGN 故障；H21 仅完成无出力验证 | 不把“改过优化”当出力通过 |
| H22 | ALIGN 通过但 +10 mA 失败；首发总预算 reason=3 | 仅开启 LTO 仍不足以完成当前出力路径 |
| H23 | CORDIC 数学自检门过严，启动即拒绝且无输出 | 失败保留，不解释成电机出力测试 |
| H24 | 数学自检和无出力通过；ALIGN fault=32，reason=2、CNT=260 | CORDIC 加速后仍有 observer 路径挤占 ADC 写入窗口 |
| H25 | 移动 observer 计算；原限额内三次 ALIGN 和所有本页短动作通过 | 改变的是执行位置/并发发布，不是把保护门调到失败值之外 |

H19 与 H24 的 原始独立审计（`../output/bench/haptic19-20260907/independent-audit.json`）、H24 审计（`../output/bench/haptic24-20260907/independent-audit.json`）分别核对 19 / 2 组 capture，仍明确 `FAULT_RECORDED`。**证据读取一致性 PASS 不等于功能 PASS。** H24 的 total=4067 包含 fault 处理开销；必须看首发 reason 和写入窗口，不能把所有超总数都误判成首发 reason=3。

H23→H24 的数值残差验收依据是本地 STM32CubeG4 v1.6.3 官方 CORDIC_CosSin 例程，readme（`../output/bench/haptic24-20260907/st-reference/CORDIC_CosSin-readme.txt`） / 源文件（`../output/bench/haptic24-20260907/st-reference/CORDIC_CosSin-main.c`）。这是 CORDIC Q1.31 数学残差验收，不是电机保护放宽；本页不引入未核实的在线表号或芯片耐压推断。

### H25 最小改动及验证

- [bench_app.c](../firmware-stm32/bench/NUCLEO_G474RE_FOC/Core/Src/bench_app.c)：4 kHz observer 在较低优先级 encoder IRQ 计算，使用两个 164-byte 状态缓冲；ADC priority=1、encoder priority=2，ADC 可抢占 encoder。
- 先记录真实采样时间，在未关中断区复制/计算 inactive buffer，再在短临界区发布 index / angle / timestamp / seq。无效 SPI 不发布有效帧。
- ADC 仅在新序号出现时复制 7 个 observer 字段，保留校准方向/零位覆盖，**不复制 PI、当前命令或触觉状态**。CORDIC 运行时仍只由 ADC 使用，不引入跨 IRQ 竞争。
- [专项测试](../firmware-stm32/tests/bench_app_diagnostic_tests.c)覆盖首帧/连续帧、±π 与计数回绕、坏 SPI、三个抢占插入点、800 μs 延迟/时钟回绕的 freshness 拒绝、校准与 PI/命令状态所有权。
- 反汇编（`../output/bench/haptic25-20260907/disassembly.txt`）核对 inactive copy 和 observer 调用均发生在发布 mask 之前；需按分支控制流看，不能只按地址排序。
- 全局最大实测 `isr_max=3351` cycles，原预算仍 3600；160 MHz 下约 20.94 μs vs 22.50 μs。这个数据只覆盖本轮已执行路径，**不是所有干扰组合的最坏执行时间证明**。

早期 concurrency-review.json（`../output/bench/haptic25-20260907/concurrency-review.json`）生成于刷写前，所以 `TargetTimingProof=PENDING` 保留为历史；本轮实机证据与最终验收中的 `OBSERVED_EXERCISED_PATHS_PASS` 补齐了已执行路径验证。`LOOP_TIMING` 的终止 stage=3/4 可能保留前一帧 foc/trajectory 字段，不把旧值当本帧执行成本。

## 6. 当前限额与不可混淆的量

| 量 | H25 当前值 |
| --- | --- |
| 母线健康窗口 | 9–15 V，有限值检查保留；沿用 H10 后窗口，未做整个窗口的物理扫压 |
| 普通相电流停止门 | 0.35 A |
| ALIGN 相电流停止门 / 电压上限 | 0.65 A / 0.60 V |
| ALIGN 实际控制 | 800 ms 渐升固定 Vd 至 0.38 V；1 s 静态、3 s 扫场、0.5 s 保持 |
| `ALIGN_CURRENT_A` | 0.40 A 是资格名义值，静态平均 Id 须 0.28–0.52 A；不是闭环目标指令 |
| 正常电压矢量上限 | 0.30 V，不是直流电源电压 |
| IQ / HAPTIC 命令幅值 | ±100 mA；不是外部电源输入限流 |
| IQ / HAPTIC 最大命令时长 | 2000 / 10000 ms；本轮只分别测试 20 / 250 ms |
| 速度 / 主机 lease | 8 rad/s / 100 ms |
| ADC / PWM | 20 kHz；ISR 3600 cycles；PWM 写入必须 DOWN 且 CNT≥320 |
| encoder / DRV SPI | encoder 4 kHz；SPI3 2.5 MHz、底部预约、150 μs 超时关断 |

最终验收脚本（`../tmp/bench/accept_haptic25_2.py`）逐个比较 H24 快照与 H25 当前关键 define，确认上述本轮没有放宽。台式电源输入电流、ADC 三相电流、dq 电流和电压矢量不是同一个量；本页仅报告实际采集到的对应量，不以电源功率估算取消本地相电流或电压门。

## 7. 独立原始数据审计及工具自身检查

审计器（`../tmp/bench/audit_frozen_captures.py`）不访问硬件：核对 BIN/MAP 哈希、按 MAP 独立解 RAM、比较两次冻结读取、重算 ring 顺序/CSV 全字段、零偏 sum/count、ADC flags / VM / 电流 / 间隔、编码器尾段、ALIGN 静态量及首故障。

H25 的 **21 组**组成：soak 1、主 ALIGN + smoke 11、首次阶梯 2、第二次阶梯 7。全部保留的 ADC 间隔为 50 μs、同步异常 0、保留段 VM 在 9–15 V 内、相电流未超过各自门，编码器保留段无 invalid；`Captured=0` 时首故障输出为 null，不把空结构的 sample=0 当故障。

审计对抗检查（`../output/bench/haptic25-20260907/audit-negative-fixtures/validation.json`）共 **9 项**：7 种破坏（CSV 原始值、第二次 RAM、ring count、零偏累加值、reader 汇总、伪造首故障、MAP 哈希）均被拒绝；原样 H25 对照通过且不凭空造故障，真实 H19 fault32 对照仍标故障。原证据哈希未变，所有破坏 fixture 另存且不删除。

工具/调度失败同样保留：

- `current-ladder` 的未稳定资格失败没有改 PASS；`current-ladder-2` 是新证据目录。
- 首次 `off-command-regression-2` 缺少 final-off 前置文件，在串口打开前退出；待 final-off 成功后使用 `off-command-regression-3`，不是覆盖重跑。
- 首次最终汇总日志（`../output/bench/haptic25-20260907/acceptance-console.log`）因 Windows PowerShell UTF-16 日志被按 UTF-8 读取而失败。修正为明确 BOM 解码后，第二次汇总（`../output/bench/haptic25-20260907/acceptance-2-console.log`）通过，断言未弱化。
- 新 observer 坏 SPI 用例曾暴露测试 fixture 未 reset `g_encoder_errors`；原失败（`../output/bench/haptic25-20260907/observer-test-fixture-failure.log`）保留，修正测试初始状态后完整重跑，没有改生产门。

## 8. 验收边界与下一步

**已验证**的是当前 NUCLEO/TI 台架的受限基本控制链、短时双向电流、八个模式入口和关断命令。**未验证**的真实缺口包括：

1. 电流计量精度/全段波形、手动扰动下的力矩和八模式手感/噪声、最大时长和反复加载。
2. 电源实际限流/输入功率、温升、回灌、外部 nFAULT→BKIN 的完整电气链路与示波器证据。
3. 产品 CET6 的 `factory_encoder_pending` 端口、ESP32/AMOLED/无线、屏幕/音量/定时器整机交互。

继续工作的优先级是补测量条件和整机端口，不是无限加大电流或延长无人值守运动。已有台架通过项不需要为了“全功能”而拆掉；未接入/未计量部分不能用 smoke 或代码存在替代验收。

离线可复核入口为 `audit_frozen_captures.py`（`../tmp/bench/audit_frozen_captures.py`）、`verify_frozen_audit_negatives.py`（`../tmp/bench/verify_frozen_audit_negatives.py`）、`accept_haptic25_2.py`（`../tmp/bench/accept_haptic25_2.py`）。它们拒绝覆盖已有报告/fixture；复跑应使用新输出，不删除原证据。台架脚本也是一次性有限动作，不能直接改成循环升流工具。

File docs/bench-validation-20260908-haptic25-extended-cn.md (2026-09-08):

# HAPTIC25 扩展实机验收（2026-09-08）

> **结论：有限台架覆盖通过，不是整机、满载或完整手感验收。**
> 固件仍为 `20260907_HAPTIC25`；本轮没有修改板上固件，没有改变供电限流/接线，没有关闭关键保护，也没有调用其他模型。

## 1. 本轮新增实测

运行测试时间：2026-09-08 04:27:46–04:29:25 UTC（纽约 00:27:46–00:29:25）。

| 项目 | 实际覆盖 | 结果 |
| --- | --- | --- |
| 重新准备和校准 | 2 次 PREPARE/零偏资格/ALIGN | 两次成功；不是复用 STOP 前的校准 |
| 指令最短边界 | IQ +1/-1 mA 各 1 ms；FREE 1 ms | 每项 21 个 ADC 总采样 |
| IQ 持续时间上限 | **仅 +1 mA**，2000 ms | 正常定时关断；不代表 ±100 mA 连续 2 s |
| HAPTIC 持续时间上限 | **FREE 零触觉指令**，10000 ms | 正常定时关断；不是全部模式满幅 10 s |
| 八类模式 | kind 0–7 各 1000 ms | 有限、无外部人工施力轨迹 smoke |
| 重复运行 | FREE 50 ms ×20 | 每次重新验证 READY/零输出稳定，没有重复 ALIGN |
| ACTIVE 命令拒绝 | PREPARE、ALIGN、IQ、HAPTIC、CLEAR、SELFTEST、FAULTTEST、CURRENT_DIAG、ENC_DIAG | 9 项拒绝；每项后验证仍为原 FREE ACTIVE |
| 运行中 STOP | FREE ACTIVE → STOP | mode=0、MOE=0、DRVOFF=1；zero/calibrated 均失效 |
| STOP 后误重启 | 未 PREPARE/ALIGN 即发 IQ/HAPTIC | 两项拒绝，桥不重新使能 |
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

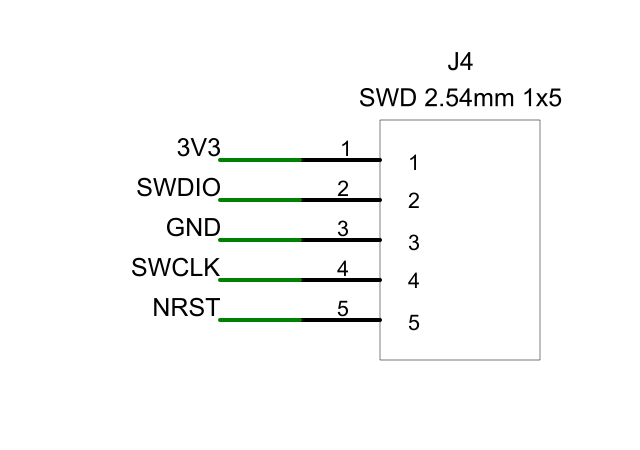
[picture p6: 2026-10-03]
hardware/pcb/stm32-foc-a-altium-r6/verification/J4_R6.png

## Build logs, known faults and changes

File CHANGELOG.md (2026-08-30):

# Changelog

All notable public changes will be recorded here. The project follows semantic versioning once stable public interfaces exist; pre-1.0 releases may intentionally change interfaces.

## Unreleased

### Added

- Clean first public engineering snapshot.
- Professional repository, contribution, security, support, and issue-management files.
- One-year evidence-gated roadmap toward a reproducible v1.0.
- STM32G474 CubeMX/Keil motor-core source and host-side tests.
- Protocol/Profile TypeScript packages, simulator, and software-only regression suite.
- DRV8316R validation-board BOM and drawing/test guidance.
- Parameterized concept CAD source and clearly labelled renders.

### Known limitations

- Factory encoder electrical/protocol details remain `PENDING_VENDOR`.
- No product PCB, motor closed loop, haptic feel, temperature, lifetime, EMC, or certification evidence exists yet.

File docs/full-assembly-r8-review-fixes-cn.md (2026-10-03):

# R8：按 R7.1 独立机械审查修改

日期：2026-09-12。保持104×98外形、收腰握环、四侧键/后电源键、单MGN7、1:1短同步带和独立固定屏幕。

当前模型入口：[整机STEP](../output/models/GL30_FULL_R8/GL30_FULL_R8_ASSEMBLY.step)、[验证JSON](../output/models/GL30_FULL_R8/verification.json)、[38类无电样件与用量](../output/print/GL30_R8_REVIEW_SAMPLES/先读_打印数量.md)、[修改与复审包](../outputs/r8-review-fixes/GL30_R8_机械修改与复审包_20260912/README_先读.md)。

主要改动：

- 输出轴、三臂架与握环改为可区分的分件连接，内外圈各有定位链；从动轮到薄盖的名义间隙增至0.65 mm。
- 滑块主安装面增加四孔L转接件；导轨、连续支架、底部背板、底盖与壳体嵌件补齐名义紧固接口。
- 电机后端三孔安装座、前端四孔转接毂、主动轮沉孔锁母及张紧槽重新建模；保留6 mm皮带工作宽度。
- 四侧键让出0.4 mm总行程；后键增加防脱肩和固定座；主旋钮增加释放止挡、弹簧座和固定弹片根部。
- 固定屏柱顶部用两只M8锁环夹托盘，按屏幕原厂图3-M2.00增加三颗模组固定螺钉。
- 重新布置电源、UVW、编码器、控制线和FFC包络，板边/支架避让随之更新；电池增加绑带空间。
- 取消额外盖玻璃、浮动装饰圈、实体蓝标；普通打印件、精密/薄金属尺寸样和假件分开标注。

全量检查包含同组分件、线束/排线、指定螺纹区域、按压、侧键、止挡、输出回转和电机张紧。以验证JSON的实际结果与文件哈希为准，旧R7.1的23项结果不沿用。

本轮没有实物装配或带电测试。弹片触发余量的条件估算仅约0.029 mm；真实开关F-S曲线、弹簧、导轨型号、轴承公差、短螺纹承载、夹紧防松、线束卡固/弯曲、连续装入路径、光学和温升仍需验证。**只交付无电尺寸样候选，不放行整套正式加工或带电力反馈。**

可复跑入口：

```powershell
.venv-cad\Scripts\python.exe hardware\cad\full_knob_assembly.py --no-render
.venv-cad\Scripts\python.exe hardware\cad\export_r8_review_samples.py
.venv-cad\Scripts\python.exe outputs\r8-review-fixes\build_release.py
```

打印样件出口仅在当前R8源码哈希和几何检查一致时运行。输出STEP/STL/3MF，不生成G-code，不连接打印机。

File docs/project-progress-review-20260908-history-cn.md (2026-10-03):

> 历史快照：以下全文保留 2026-09-08 的审查及另行授权续测记录。文中的“当前”“本轮”均指当时，不代表 H26 新源码、2026-09-09 采购/设计状态或此刻硬件状态。最新汇总见[项目总进度](project-progress-review-20260908-cn.md)。

# 项目进展与开源借鉴审查 — 2026-09-08

> 审查对象是当前 HAPTIC25 工作树及已保存的台架证据，不是早期 H3 快照。本文区分“已有实测”“审查复核”“建议下一步”。两位外部审查者只收到证据摘要，没有操作硬件；主线程审查阶段也未操作硬件。期间用户另行要求的短时实机续测已单列于 §3.1，不与离线审查混计。全程未刷写固件、改接线、调电源或修改生产代码。

## 1. 问题与当前判断

用户要求：带上千问和 DeepSeek，整理项目进展，评估能否继续参考别人的项目进行修改。

**主线程判断：可以借鉴，优先借鉴触觉行为和应用组织；保留已验证的 H25 电流控制底层，不立即全栈迁移。** 此结论不等于现有手感已经合格，也不承诺任何开源项目的参数可直接用于 GL30。

成功标准是：核对当前证据；两位审查者实际参与；对关键分歧交叉质询；明确可借鉴内容、禁搬内容、修改落点和验证条件。此轮交付是审查和路线，不是未经授权改写整套控制软件。

## 2. 现在到底做到哪里

| 模块 | 已有事实 | 仍缺什么 |
| --- | --- | --- |
| NUCLEO + TI + GL30/AS5048A | H25 有真实 ALIGN、双向小电流、八模式定时 smoke 证据 | 不能据此宣称整机/满载/完整手感合格 |
| 实时控制 | 20 kHz ADC 电流环、4 kHz 编码器 observer、CORDIC；H25 将 observer 计算移出 ADC 高优先级路径 | 实测最坏时间不是所有未来路径的 WCET 保证 |
| 电流闭环 | ±10/25/50/100 mA 各 20 ms；±100 mA 原始 ADC 近似重建约 +95.27/-93.07 mA | 不是外部电流仪表/力矩计标定，也不是 ±100 mA 持续 2 s 验收 |
| 八种触觉 | 自由、阻尼、档位、弹簧、限位、摩擦、惯性、速度各有有限时长入口运行记录 | 没有完整人工角度/外力轨迹与主观手感验收 |
| 状态机/通信 | 受限 STOP、未校准拒绝、ACTIVE 命令拒绝、约 100 ms 租约失效关断及通信压力验证 | 外部 nFAULT→BKIN、真实失电/看门狗整链仍需对应物理验证 |
| PC | 协议、Profile 校验、模拟设备、测试框架；SIM_ONLY E2E | 不是实体设备端到端；高级 Profile 字段不是运行时能力 |
| ESP32/AMOLED | 当前目录是 README 工程框架，尚无可烧录 ESP-IDF 应用 | UART 实体收发、屏幕/UI、音量/计时器、无线均需实现/整机验证 |
| 产品 STM32 CET6 | 工程能构建，产品编码器端口仍有 pending 门禁 | 不能直接用 NUCLEO 的实测替代产品端口验收 |
| CAD/打印 | 有黑色收腰旋环、蓝标、固定黑屏过渡方案及三件式夹具数字模型 | 打印配合、承载、屏固定/穿线/传扭、轴向保持、公差与“关机看不出屏幕”的光学效果未完整验证 |
| 电池/主板 | 3S 充电、电源路径、回灌处理是候选工程方案 | 未达制造/电气/温升/回灌放行 |

详细实测以 [H25 基线](bench-validation-20260907-haptic25-cn.md)和 [H25 扩展验收](bench-validation-20260908-haptic25-extended-cn.md)为准。历史失败仍保留；不把 H19/H24 失败抹掉，也不把它们当成 H25 当前失败。

### 一个不能被 smoke 掩盖的例子

扩展数据中 `haptic-7-1000ms` 的目标是 1 rad/s；启动前角度 -701 mrad，结束后 -698 mrad，末帧速度 -223 mrad/s。净位移约 0.003 rad，**没有证明目标速度跟踪**。起终点也不足以还原中间是否往返，后续需看带时间戳轨迹。

复核其最后 2048 个编码器点，间隔为 250 μs，约 0.512 s 尾段净位移为 -0.00115049 rad；最后 512 个 ADC 点近似重建 Iq 均值约 -24.18 mA，校准方向为 -1。这些尾段仍不能证明全程速度跟踪，也不能单凭电流符号或末帧速度确定机械/控制根因。

源码 `bench_haptics.c` 设速度比例系数 0.001 N·m/(rad/s)，`haptics.c` 没有该外环的积分项；静止时理论 Iq 参考量级约 26.3 mA。这是源码计算，不是“不动必然由摩擦/无积分导致”的证明。不要直接加积分或提高限流来代替排查。

## 3. 本轮独立复核

- 重新执行源码身份校验：37 个项目输入与 H25 规范化哈希一致。
- 新建独立 Debug 构建目录，重新构建并运行当前 C 测试：7/7 通过。
- 从原始 RAM/MAP/CSV 重新审计扩展 37 组 capture：一致性通过；预期租约 fault=4 仍保留，不改成“无故障”。
- 历史发布验证记录还有 ASan+UBSan、Release+LTO、TS 21/21、viewer 18/18、两目标 Keil 构建。本轮没有重跑这些项目，不能混成“本轮全部复测”。
- 合格台架镜像：60136 bytes，SHA-256 `B98161DB5EDAE02EBCE29F0F645405C2DA73CC1B99387A67D55181E98964DFB7`。
- 交给两位审查者的最后硬件关断记录在 2026-09-08 04:35 UTC：MOE=0、DRVOFF=1。它是审查包的历史记录；随后单独续测的更新见下节。

本轮原始审查和复核产物在本地 `output/review-20260908/`；代码/日志不因文档整理而改写。长动作只保存采样尾段，ADC 近似重建不是独立模拟计量。

### 3.1 用户另行授权的短时实机续测

2026-09-08 12:23 UTC，主线程按用户“继续控制电路和电机进行测试”的要求，单独运行一次受限序列。未提高限流、未移除保护、未循环清错/重试：

- 1 次重新 PREPARE/校零/ALIGN，通过；ALIGN 的 ADC 总采样为 90001。
- ±25/50/100 mA 各 20 ms，共 6 次；各 401 个 ADC 总采样，正常定时停止。
- 阻尼、档位、弹簧各 250 ms，共 3 次；各 5001 个 ADC 总采样，正常定时停止。
- 10 组 RAM/MAP/CSV 采样再次独立审计通过；无新增编码器、ADC、时序或 UART 错误。最大 ISR 仍为 3351 cycles。
- 开始前整区读回仍匹配 H25 镜像；12:25 UTC 的 SWD HOTPLUG 只读关断检查确认 MOE=0、通道使能=0、六路 PWM 输入低、DRVOFF=1、fault=0。未物理关闭电源。

原始 [运行结果](../output/bench/haptic25-resume-20260908/run-1/validation.json)、[独立审计](../output/bench/haptic25-resume-20260908/independent-audit.json)、[最后关断核查](../output/bench/haptic25-resume-20260908/final-off/validation.json)保留在本机。这些是短时控制链复测，不是手感验收；外部两模型没有看到这一轮新增数据，三方审查结论基于此前共同证据包，新增结果仅由主线程补充验收。

## 4. 借鉴哪些项目，具体改哪里

| 项目 | 已核对的内容 | 建议落点 | 明确不搬 |
| --- | --- | --- | --- |
| SmartKnob | 有状态逻辑档位、跨档阈值、中心死区、配置切换与状态发布 | STM32 低频触觉行为层；先做宽档位和无冲击模式切换 | 电压/归一化 strength、PID 数值、校准零位、引脚和硬件 |
| X-Knob | 结构化预设、应用切换和电机状态向应用发布 | ESP32 最小应用组织；先一个档位/数值界面 | 整套 3PWM/MT6701/5 V 底层，或复制全部应用框架 |
| SimpleFOC | PID 的积分限幅、输出斜率限制、重置等实现模式；有 DRV8316 软件驱动接口 | 未来确有外环需求时作算法与接口参照 | 直接替换 H25 ADC/PWM/故障时序；把默认电压控制等同电流控制 |

对应的一手源码：
- [SmartKnob motor_task.cpp](https://github.com/scottbez1/smartknob/blob/4eb988399c3fda6ffd3006772856093dfe9adb86/firmware/src/motor_task.cpp)，固定修订 `4eb9883`；重点看档位状态、阈值与死区，不照搬其 `PID_velocity` 名称代表的用途。
- [X-Knob motor.cpp](https://github.com/SmallPond/X-Knob/blob/05be44fc62b27c4fa941aabd2a7e9b2553f91fb9/1.Firmware/src/hal/motor.cpp)，固定修订 `05be44f`；预设和逻辑事件适合参考，默认参数不是本机物理量。
- [SimpleFOC PID](https://github.com/simplefoc/Arduino-FOC/blob/7f9c45fa3af42eec993b807b97dc544f50975e73/src/common/pid.cpp)，本轮固定 master 为 `7f9c45f`；[DRV8316 接口](https://github.com/simplefoc/Arduino-FOC-drivers/blob/ed05aa1644de36cbd19f43e8ea5c3edb643cefa9/src/drivers/drv8316/drv8316.h)，固定 `ed05aa1`。电路结论仍必须回到 TI 对应 R 版手册/原理图，不由此决定接线或解除保护。

现有 [第三方说明](../THIRD_PARTY_NOTICES.md)已记录 SmartKnob Apache-2.0、X-Knob MIT；本轮也核对了固定修订的 [SmartKnob LICENSE.txt](https://github.com/scottbez1/smartknob/blob/4eb988399c3fda6ffd3006772856093dfe9adb86/LICENSE.txt)与 [X-Knob LICENSE.md](https://github.com/SmallPond/X-Knob/blob/05be44fc62b27c4fa941aabd2a7e9b2553f91fb9/LICENSE.md)。此次只做研究引用，没有复制上游代码/CAD/素材。后续如实际引入源码，必须核对所取文件的许可证、归属及保留要求，锁定修订；不能因“开源”直接复制全套设计。

### 最重要的语义差距

现在 `haptics.c` 的档位是周期正弦力矩，不是带逻辑档位记忆的 snap 状态机。Profile 中虽已有 `snapRatio/asymmetry/magneticPositions`，但没有证明实体部署支持这些语义；SmartKnob/X-Knob 转换器也未实现。

应在部署/编译边界显式拒绝不支持的效果，或在用户明确选择后给出降级报告。**Profile 校验通过不代表设备能呈现。** 现阶段不能凭未实现的转换链断言“正在静默丢字段”，但必须防止未来如此实现。

## 5. 建议执行顺序与验收

1. **先给已有弹簧、阻尼和宽档位建立真实行为基线。**
   - 同一装配条件下记录慢速正反转、跨中心/跨档、停止和切换的角度、目标、Iq、状态。
   - 比较力的方向、中心附近抖动、跨档逻辑、限幅与退出；不把无人工输入的计时完成当作手感通过。
   - 无独立力矩计时可做方向/重复性与主观比较，不宣称绝对力矩精度。

2. **只补一个有状态宽档位 + 无冲击切换。**
   - 代码责任落在 `firmware-stm32/haptics/` 及必要的状态定义；不往 20 kHz ADC 路径塞 UI、配置解析或复杂计算。
   - 先定义逻辑方向、原点、相邻档切换阈值、中心死区、端点、掉帧跨多档和重置规则；死区与迟滞不是同一件事。
   - 先不一起实现非对称、稀疏磁点、复杂纹理或自动中心漂移。保留物理 Nm/A 限幅，宽度为 rad；弹簧刚度应标 N·m/rad，不与峰值 N·m 混淆。
   - 单元轨迹覆盖正反向、阈值两侧、边界抖动、跳帧、多圈、模式切换和输出限幅；离线通过后再受限实机 A/B。新代码生成新镜像身份和新验收，不能继续套用 H25 旧哈希。

3. **完成一个真实应用闭环，而非继续增加演示模式。**
   - ESP32 先成为可构建/可烧录应用，收一条真实角度/档位状态并显示；再选音量或计时器之一连接动作与反馈。
   - 把界面事件与电机控制周期分离。实体接线按实际产品端口核对，不从 PC 模拟器的电压/电流字段推断硬件状态。
   - 验收为一次可重复“转动→数值/屏幕→应用动作→反馈”的真实演示，并验证断链处理。
   - 无线、电池、复杂 Home Assistant 配置保留后续实施，不冒充已经做完；机械固定屏/承载/穿线和回灌等 HOLD 项继续作为各自放行条件。

整体迁移 SimpleFOC 不是永久禁止，而是当前缺少必要性证据。若后续证明 H25 的结构性限制无法以小改动满足需求，再以同一硬件、同一限幅和同一测试集比较替代内核，不凭项目名选胜者。

## 6. 三方独立审查与交叉质询

采用三方审查流程：同一份中性证据包分别提交；主线程在读取外部结果前保存独立判断；再把分歧与可核对反例送交双方进行第二轮。两轮都完成，不是降级双人审查。外部模型没有读取整个仓库或进行实机实验；证据包明确压缩了源码、长日志与采样，不能把模型回答当作新增实测。

| 审查者 | 首轮判断 | 交叉质询后的变化 | 任务证据 |
| --- | --- | --- | --- |
| 主线程 | 保留 H25；先补真实行为基线、单一宽档位和应用闭环 | 维持方向，驳回错误的文档过度宣称、任意新门限及全高级字段一次实现 | `primary-initial.txt`、`primary-cross-exam.txt` |
| DeepSeek V4 Pro | 保留 H25，但误判现报告已声称速度/手感通过；建议同时加入多个高级字段 | 撤回该误判、旧哈希继续通过和已证实静默丢字段等说法；同意收敛到宽档位、死区、切换 | 首轮 `20260908120838-c6ddc2f3def6`；二轮 `20260908121521-e27e07165105` |
| 千问 Qwen3.8 | 保留 H25；强调独立计量，但提出 3200/3300 cycles 新门与更宽前置验收 | 撤回任意新门、p99 替代最大延迟、另建等级框架及完整计量阻塞每次离线工作；同意优先窄范围能力 | 首轮 `c9737d1bf6b7`；二轮 `57fa101f1fe8` |

原始证据包和四份最终回答保存在 `output/review-20260908/`。两位模型均自然完成，未截断续写；没有采用模型自报的百分比作为统计置信度。

**共识与理由：** 当前没有证明整体换 SimpleFOC 会解决一个具体的结构性问题，而已有 H25 的采样/时序/关断资格会因整体迁移重做。SmartKnob 的有状态档位比当前正弦力矩更贴近“明确档位”的需求；X-Knob 的应用状态发布可帮助完成实际界面闭环。这是源码与证据支持的判断，不以三票一致作为证明。

**仍不直接接受的意见：**

- 千问二轮仍称“ALIGN 0.33 A 限值”。约 0.33 A 是既有测量量级，**不是保护限值**。当前 ALIGN 相电流停止门为 0.65 A，另有 0.28–0.52 A 末段平均 Id 资格；正常 IQ/HAPTIC 指令上限为 ±0.10 A。三者不可混用。
- 独立电流计量有价值，但不是纯离线算法实现或定性主观比较的统一前置；定量电流/力矩/性能与产品放行必须有相应测量。普通直流表不能直接测旋转坐标系 Iq。
- 速度模式尚无稳速性能资格，但不因此直接删除用户需要的功能或盲加 PI；先用时间戳轨迹、饱和与实际响应区分原因。
- 发生故障不自动意味着应换底层。先停止具体实验、保留首故障并定位；只有结构性限制有证据，才评估替代实现。

**最强反对意见 / 暂停条件：** 同一 ADC 与软件变换的自洽，不等于物理相电流、绝对力矩和带载安全已证明。若新增测量与电流方向/幅值矛盾，或出现失控、异常温升、时序超限、机械卡滞，应暂停对应实机增强，不靠提高阈值或反复 CLEAR 前进。外部故障整链、热、回灌和机械 HOLD 仍是相应产品放行条件。

**最低成本的区分实验：** 先用确定的正反向角度序列离线比较当前正弦档位与单一有状态宽档位，覆盖中心死区、阈值往返、跨多档和模式切换；随后在同一装配、同一限幅下做短时 A/B，记录目标、角度、Iq 和最大执行时间。人工触感对比与方向/重复性可以先做，绝对力矩性能另用计量验证。ESP32 并行目标是可构建的一条真实状态接收/显示链，不以模拟数据代替。

**最终建议与置信度：** 对“保留 H25 底层、借鉴上层行为、补真实应用闭环”的当前路线置信度较高；对具体手感参数、速度根因、带载性能和整机可靠性仍不足。若同条件验证证明 H25 的结构无法满足必要时序/控制需求，而替代实现通过同一测试集，可改变保留底层的判断；若档位状态机 A/B 未改善重复性或切换反而冲击，则回退该行为改动。任何新固件都使用新镜像身份与新验收，旧 H25 留作基线。

## 7. 本轮实际改动范围

- 新增这份进展/借鉴报告。
- 纠正当前架构文档里的旧“仍未带转”状态；把 9 月 5 日复盘明确标记为历史快照，避免旧 B1/首测限值成为当前操作指令。
- 审查没有改生产代码、单元测试、硬件保护、CAD、供电或接线；不进行 Git 提交、推送或发布。
- 用户单独授权续测时，新增本地有限测试脚本 `tmp/bench/resume_haptic25_bounded_20260908.ps1` 和 §3.1 证据。脚本沿用既有保护与有限测试助手；终端摘要的字典显示问题已修正，真实 JSON/串口/采样结果独立核对，不因摘要显示为空而虚构通过或重新驱动电机。

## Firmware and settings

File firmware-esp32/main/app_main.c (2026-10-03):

#include <errno.h>
#include <inttypes.h>
#include <stddef.h>
#include <stdint.h>
#include <stdio.h>
#include <stdlib.h>
#include <string.h>

#include "driver/usb_serial_jtag.h"
#include "driver/usb_serial_jtag_vfs.h"
#include "esp_err.h"
#include "esp_heap_caps.h"
#include "esp_log.h"
#include "esp_timer.h"
#include "freertos/FreeRTOS.h"
#include "freertos/queue.h"
#include "freertos/task.h"
#include "gl30_board.h"
#include "gl30_demo.h"
#include "gl30_motor.h"
#include "kk_oled.h"
#include "kk_ui_config.h"
#include "gl30_display_trace.h"
#include "gl30_settings_store.h"

#define GL30_CONSOLE_LINE_SIZE 64U
#define GL30_CONSOLE_READ_SIZE 32U
#define GL30_INPUT_QUEUE_SIZE 64U
#define GL30_TIME_MIN_UNIX 946684800ULL
#define GL30_TIME_MAX_UNIX 4102444800ULL
#define GL30_TARGET_FPS 60U
#define GL30_PRESENT_PERIOD_US 16667ULL

static const char *TAG = "gl30_app";
typedef enum { INPUT_TOUCH, INPUT_CONSOLE, INPUT_LINE_OVERFLOW } input_kind;
typedef struct {
    input_kind kind;
    uint32_t now_ms;
    uint64_t arm_generation;
    gl30_menu_sample motor;
    union {
        struct { int16_t x, y; bool pressed, valid; } touch;
        char line[GL30_CONSOLE_LINE_SIZE];
    } value;
} input_event;
typedef struct {
    uint32_t samples, drops, max_poll_us;
} input_stats;

static QueueHandle_t s_inputs;
static TaskHandle_t s_input_task;
static TaskHandle_t s_ui_task;
static esp_timer_handle_t s_frame_timer;
static portMUX_TYPE s_input_stats_lock = portMUX_INITIALIZER_UNLOCKED;
static input_stats s_input_stats;
static uint32_t s_last_loop_us, s_last_tick_us;
static uint32_t s_frame_deadline_drops;
static uint64_t s_last_idle_yield_us;
/* Only the input task owns the parser and its partial line. */
static char s_console_line[GL30_CONSOLE_LINE_SIZE];
static uint8_t s_console_read[GL30_CONSOLE_READ_SIZE];
static size_t s_console_line_length;
static bool s_console_line_overflow;
static uint64_t s_console_arm_generation;
static gl30_preferences s_observed_preferences,s_saved_preferences;
static gl30_settings_load_result s_preferences_load;
static uint64_t s_preferences_changed_us,s_preferences_attempt_us,s_preferences_token;
static esp_err_t s_preferences_error;
static bool s_preferences_pending;
typedef enum { SETTINGS_IDLE,SETTINGS_RELEASE,SETTINGS_RESUME } settings_stage;
static settings_stage s_preferences_stage;

/* UI owner only. A single immutable blob is written while both reservations
 * are held. Input may queue during Flash; generation fences survive that gap. */
static void preferences_service(uint64_t now)
{
    gl30_preferences current;
    if(!gl30_preferences_capture(gl30_demo_state(),&current)) {
        s_preferences_error=ESP_ERR_INVALID_ARG;
        return;
    }
    if(!gl30_preferences_equal(&current,&s_observed_preferences)) {
        s_observed_preferences=current; s_preferences_changed_us=now;
    }
    s_preferences_pending=!gl30_preferences_equal(&current,&s_saved_preferences);
    gl30_motor_status motor;
    gl30_motor_snapshot(&motor);
    if(s_preferences_stage==SETTINGS_RESUME) {
        if(motor.control_ready && motor.maintenance_token==0) {
            s_preferences_token=0; s_preferences_stage=SETTINGS_IDLE;
        }
        return;
    }
    if(s_preferences_stage==SETTINGS_IDLE) {
        if(!s_preferences_pending || !gl30_settings_store_available() ||
           now<s_preferences_changed_us || now-s_preferences_changed_us<1500000u ||
           (s_preferences_attempt_us!=0 && now>=s_preferences_attempt_us &&
            now-s_preferences_attempt_us<5000000u)) return;
        s_preferences_attempt_us=now;
        s_preferences_token=gl30_motor_maintenance_begin();
        if(s_preferences_token==0) {
            s_preferences_error=ESP_ERR_INVALID_STATE;
            return;
        }
        s_preferences_stage=SETTINGS_RELEASE;
        return;
    }
    if(now<s_preferences_attempt_us || now-s_preferences_attempt_us>=2000000u) {
        /* No partner/DMA completion: no Flash, retain pending preferences. */
        gl30_demo_maintenance(false);
        gl30_motor_maintenance_end(s_preferences_token);
        s_preferences_error=ESP_ERR_TIMEOUT;
        s_preferences_stage=SETTINGS_RESUME;
        return;
    }
    if(!motor.maintenance_ready || motor.maintenance_token!=s_preferences_token ||
       now<s_preferences_changed_us || now-s_preferences_changed_us<1500000u) return;
    gl30_demo_maintenance(true);
    OLED_Poll();
    if(!gl30_demo_display_ok()) {
        gl30_demo_maintenance(false);
        gl30_motor_maintenance_end(s_preferences_token);
        s_preferences_error=ESP_FAIL;
        s_preferences_stage=SETTINGS_RESUME;
        return;
    }
    if(!gl30_board_display_maintenance_begin()) return;
    if(!gl30_motor_maintenance_claim(s_preferences_token)) {
        gl30_board_display_maintenance_end();
        gl30_demo_maintenance(false);
        gl30_motor_maintenance_end(s_preferences_token);
        s_preferences_error=ESP_ERR_INVALID_STATE;
    } else {
        const gl30_preferences snapshot=current;
        s_preferences_error=gl30_settings_store_write(&snapshot,s_preferences_token);
        if(s_preferences_error==ESP_OK) {
            s_saved_preferences=snapshot;
            s_preferences_pending=false;
            ESP_LOGI(TAG,"preferences saved; motor remains unarmed");
        } else {
            ESP_LOGE(TAG,"preferences write failed (%s); durable outcome uncertain",
                esp_err_to_name(s_preferences_error));
        }
        gl30_board_display_maintenance_end();
        gl30_demo_maintenance(false);
        gl30_motor_maintenance_end(s_preferences_token);
    }
    s_preferences_stage=SETTINGS_RESUME;
}

static input_stats input_snapshot(void)
{
    input_stats result;
    portENTER_CRITICAL(&s_input_stats_lock);
    result = s_input_stats;
    portEXIT_CRITICAL(&s_input_stats_lock);
    return result;
}

static void enqueue_input(const input_event *event)
{
    if (xQueueSend(s_inputs, event, 0) != pdTRUE) {
        /* Lost input can include a stop or a press/release. Do not wait for
         * the UI consumer to notice the overflow before disarming. */
        gl30_motor_stop();
        portENTER_CRITICAL(&s_input_stats_lock);
        ++s_input_stats.drops;
        portEXIT_CRITICAL(&s_input_stats_lock);
    }
    xTaskNotifyGive(s_ui_task);
}
static void frame_deadline(void *argument)
{
    (void)argument;
    xTaskNotifyGive(s_ui_task);
}

static bool parse_time(const char *line, uint64_t *unix_seconds)
{
    const char *text;
    char *end;
    unsigned long long value;
    if (strncmp(line, "TIME", 4) != 0) return false;
    text = line + 4;
    if (*text != ' ' && *text != '\t') return false;
    while (*text == ' ' || *text == '\t') ++text;
    if (*text < '0' || *text > '9') return false;
    errno = 0;
    value = strtoull(text, &end, 10);
    if (errno == ERANGE || end == text) return false;
    while (*end == ' ' || *end == '\t') ++end;
    if (*end != '\0' || value < GL30_TIME_MIN_UNIX || value > GL30_TIME_MAX_UNIX)
        return false;
    *unix_seconds = (uint64_t)value;
    return true;
}

/* Runs on the UI task. The sampler never calls UI code or writes console logs. */
static void console_status(void)
{
    gl30_board_stats board;
    gl30_board_get_stats(&board);
    input_stats input = input_snapshot();
    gl30_demo_metrics ui_metrics;
    gl30_demo_get_metrics(&ui_metrics);
    gl30_render_profile render_profile;
    gl30_render_get_profile(&render_profile);
    OLED_Metrics oled;
    OLED_GetMetrics(&oled);
    gl30_motor_status motor;
    gl30_motor_snapshot(&motor);
    printf("GL30_STATUS {\"metric_schema\":2,\"frame_interval_ms\":%u,\"target_fps\":%u,\"frame_period_us\":%u,\"frame_deadline_drops\":%" PRIu32 ",\"uptime_ms\":%" PRId64
           ",\"internal_free\":%u,\"psram_free\":%u,\"stack_free\":%u,"
           "\"frames_sent\":%" PRIu32 ",\"frame_errors\":%" PRIu32
           ",\"last_frame_us\":%" PRIu32 ",\"max_frame_us\":%" PRIu32
           ",\"copy_us\":%" PRIu32 ",\"copy_wait_us\":%" PRIu32
           ",\"copy_submit_us\":%" PRIu32 ",\"copy_span_us\":%" PRIu32
           ",\"submit_us\":%" PRIu32 ",\"wait_us\":%" PRIu32
           ",\"loop_us\":%" PRIu32 ",\"tick_us\":%" PRIu32
           ",\"draw_us\":%" PRIu32 ",\"ui_update_us\":%" PRIu32
           ",\"ui_p95_us\":%" PRIu32 ",\"ui_frames\":%" PRIu32
           ",\"menu_profile_us\":[%" PRIu32 ",%" PRIu32 ",%" PRIu32 ",%" PRIu32 ",%" PRIu32 "]"
           ",\"motor_connected\":%s,\"motor_armed\":%s,\"motor_menu_valid\":%s"
           ",\"motor_state\":%u,\"motor_fault_bits\":%" PRIu32 ",\"motor_feedback_rx_us\":%" PRIu64
           ",\"motor_rx_fast\":%" PRIu32 ",\"motor_rx_haptic\":%" PRIu32
           ",\"motor_tx\":%" PRIu32 ",\"motor_rx_errors\":%" PRIu32
           ",\"motor_tx_errors\":%" PRIu32 ",\"motor_poll_max_us\":%" PRIu32
           ",\"motor_stop_generation\":%" PRIu64
           ",\"motor_zero_confirmed\":%s,\"motor_zero_command_nonce\":%" PRIu32
           ",\"motor_zero_sent_us\":%" PRIu64 ",\"motor_zero_feedback_us\":%" PRIu64
           ",\"motor_control_ready\":%s,\"motor_lease_generation\":%" PRIu64
           ",\"motor_maintenance_token\":%" PRIu64 ",\"motor_maintenance_ready\":%s"
           ",\"preferences_load\":%d,\"preferences_pending\":%s"
           ",\"preferences_stage\":%d,\"preferences_error\":%d"
           ",\"input_samples\":%" PRIu32 ",\"input_queue_drops\":%" PRIu32
           ",\"input_poll_max_us\":%" PRIu32 ",\"input_stack_free\":%u"
           ",\"touch_reads\":%" PRIu32 ",\"touch_errors\":%" PRIu32
           ",\"touch_presses\":%" PRIu32 ",\"touch_pressed\":%s,"
           "\"last_touch\":[%d,%d],\"clear_us_total\":%" PRIu64
           ",\"compare_us_total\":%" PRIu64 ",\"clear_pixels_total\":%" PRIu64
           ",\"retire_clear_us_total\":%" PRIu64 ",\"retire_clear_pixels_total\":%" PRIu64
           ",\"retire_clear_calls\":%" PRIu32
           ",\"clear_calls\":%" PRIu32 ",\"full_clears\":%" PRIu32
           ",\"identical_frames\":%" PRIu32 ",\"compare_calls\":%" PRIu32
           ",\"skipped_compares\":%" PRIu32 ",\"display_stack_free\":%" PRIu32
           ",\"dma_largest_free\":%u,\"accepted_frames\":%" PRIu32
           ",\"last_frame_id\":%" PRIu32 ",\"ui\":%s}\n",
           (unsigned)KK_UI_FRAME_INTERVAL_MS,(unsigned)GL30_TARGET_FPS,(unsigned)GL30_PRESENT_PERIOD_US,
           s_frame_deadline_drops,esp_timer_get_time() / 1000,
           (unsigned)heap_caps_get_free_size(MALLOC_CAP_INTERNAL | MALLOC_CAP_8BIT),
           (unsigned)heap_caps_get_free_size(MALLOC_CAP_SPIRAM),
           (unsigned)uxTaskGetStackHighWaterMark(NULL),
           board.frames_sent, board.frame_errors, board.last_frame_us, board.max_frame_us,
           board.last_copy_us, board.last_copy_us, board.last_copy_submit_us, board.last_copy_span_us, board.last_submit_us, board.last_wait_us,
           s_last_loop_us, s_last_tick_us, ui_metrics.last_draw_us, ui_metrics.last_update_us,
           ui_metrics.p95_update_us, ui_metrics.frames,
           render_profile.menu_layout_us,render_profile.menu_disc_us,render_profile.menu_ring_us,
           render_profile.menu_icon_us,render_profile.menu_label_us,
           motor.connected?"true":"false",motor.armed?"true":"false",motor.sample.valid?"true":"false",
           (unsigned)motor.feedback.state,motor.feedback.fault_bits,motor.feedback.received_us,
           motor.fast_frames,motor.haptic_frames,motor.tx_frames,motor.rx_errors,motor.tx_errors,motor.max_poll_us,
           motor.stop_generation,
           motor.zero_confirmed?"true":"false",motor.zero_command_nonce,
           motor.zero_sent_us,motor.zero_feedback_us,
           motor.control_ready?"true":"false",motor.lease_generation,
           motor.maintenance_token,motor.maintenance_ready?"true":"false",
           (int)s_preferences_load,s_preferences_pending?"true":"false",
           (int)s_preferences_stage,(int)s_preferences_error,
           input.samples, input.drops, input.max_poll_us,
           (unsigned)uxTaskGetStackHighWaterMark(s_input_task),
           board.touch_reads, board.touch_errors, board.touch_presses,
           board.touch_pressed ? "true" : "false", board.last_touch_x, board.last_touch_y,
           oled.clear_us, oled.compare_us, oled.clear_pixels,
           oled.retire_clear_us, oled.retire_clear_pixels, oled.retire_clear_calls,
           oled.clear_calls,
           oled.full_clears, oled.identical_frames,oled.compares,oled.skipped_compares,board.display_stack_free,
           (unsigned)heap_caps_get_largest_free_block(MALLOC_CAP_INTERNAL | MALLOC_CAP_DMA),
           board.accepted_frames,board.last_frame_id,
           gl30_demo_json());
    fflush(stdout);
}

static void console_handle_line(const char *line, uint32_t received_ms,
                                uint64_t arm_generation)
{
    uint64_t unix_seconds;
    if (strcmp(line, "STATUS") == 0) {
        console_status();
    } else if (strcmp(line,"TRACE START")==0) {
        gl30_display_trace_start();
    } else if (strcmp(line,"TRACE STOP")==0) {
        gl30_display_trace_stop();
    } else if (strcmp(line,"TRACE DUMP")==0) {
        gl30_display_trace_dump();
    } else if (strcmp(line,"MOTOR ARM")==0) {
        if (!gl30_motor_arm(arm_generation))
            ESP_LOGW(TAG, "MOTOR ARM discarded: a newer stop invalidated the command");
    } else if (strcmp(line,"MOTOR OFF")==0) {
        /* The sampler already stopped the motor before enqueueing this line.
         * Repeating it here would invalidate a genuinely newer ARM command. */
    } else if (strcmp(line, "BUTTON 0") == 0 || strcmp(line, "BUTTON 1") == 0) {
        gl30_demo_button(line[7] == '1', received_ms);
    } else if (strncmp(line, "ROTATE ", 7) == 0) {
        char *end;
        errno = 0;
        long steps = strtol(line + 7, &end, 10);
        if (errno == 0 && end != line + 7 && *end == '\0' && steps >= -360 && steps <= 360)
            gl30_demo_rotate((int16_t)steps);
        else
            ESP_LOGW(TAG, "ROTATE requires an integer from -360 to 360");
    } else if (parse_time(line, &unix_seconds)) {
        gl30_demo_set_clock(unix_seconds);
        ESP_LOGI(TAG, "clock set to %" PRIu64, unix_seconds);
    } else {
        ESP_LOGW(TAG, "use STATUS, TIME <unix_seconds>, BUTTON 0/1, ROTATE <steps>, MOTOR ARM/OFF");
    }
}
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
void app_main(void)
{
    uint32_t last_event_ms = (uint32_t)(esp_timer_get_time() / 1000);
    uint64_t next_frame_us=0;
    const uint64_t frame_period_us=GL30_PRESENT_PERIOD_US;
    uint32_t observed_drops = 0;
    s_ui_task=xTaskGetCurrentTaskHandle();
    gl30_preferences restored;
    s_preferences_load=gl30_settings_store_boot_load(&restored);
    if (!console_init() || !gl30_demo_init(last_event_ms, 0U)) {
        ESP_LOGE(TAG, "display/UI/USB initialization failed");
        return;
    }
    if(s_preferences_load==GL30_SETTINGS_LOADED)
        (void)gl30_demo_apply_preferences(&restored);
    if(!gl30_preferences_capture(gl30_demo_state(),&s_observed_preferences) || !gl30_motor_init()) {
        ESP_LOGE(TAG,"preferences/motor initialization failed"); return;
    }
    s_saved_preferences=s_observed_preferences;
    ESP_LOGI(TAG,"preferences boot load=%d, storage available=%d",
        s_preferences_load,gl30_settings_store_available());
    s_inputs = xQueueCreate(GL30_INPUT_QUEUE_SIZE, sizeof(input_event));
    if (s_inputs == NULL) {
        ESP_LOGE(TAG, "input queue allocation failed");
        return;
    }
    const esp_timer_create_args_t timer_args={.callback=frame_deadline,.name="gl30_frame"};
    ESP_ERROR_CHECK(esp_timer_create(&timer_args,&s_frame_timer));
    if (xTaskCreatePinnedToCore(input_task, "gl30_input", 4096, NULL, 3,
                                &s_input_task, 1) != pdPASS) {
        ESP_LOGE(TAG, "input task creation failed");
        vQueueDelete(s_inputs);
        return;
    }
    ESP_LOGI(TAG, "GL30 ready; input 100Hz; USB: STATUS, TIME, BUTTON 0/1, ROTATE -360..360");
    for (;;) {
        int64_t started_us = esp_timer_get_time();
        input_stats input = input_snapshot();
        if (input.drops != observed_drops) {
            /* Overflow loses gesture state: clear pending input conservatively.
             * A new ARM must be captured after this cleanup to be accepted. */
            gl30_motor_stop();
            gl30_demo_cancel_input();
            xQueueReset(s_inputs);
            observed_drops = input.drops;
            ESP_LOGW(TAG, "input queue overflow; motor stop requested and pending gesture cancelled");
        }
        /* Bound each batch so a producer cannot starve painting. */
        UBaseType_t pending = uxQueueMessagesWaiting(s_inputs);
        for (UBaseType_t index = 0; index < pending; ++index) {
            input_event event;
            if (xQueueReceive(s_inputs, &event, 0) != pdTRUE) break;
            /* Angle snapshot belongs to this input sample. A later drawing
             * completion must not change which item a click selects. */
            gl30_demo_motor_menu(event.motor.epoch,event.motor.session,event.motor.position,
                event.motor.fraction,event.motor.valid,event.now_ms);
            if (event.kind == INPUT_TOUCH) {
                if (event.value.touch.valid)
                    gl30_demo_touch(event.value.touch.x, event.value.touch.y,
                                    event.value.touch.pressed, event.now_ms);
                else
                    gl30_demo_cancel_input();
            } else if (event.kind == INPUT_CONSOLE) {
                console_handle_line(event.value.line, event.now_ms, event.arm_generation);
            } else {
                ESP_LOGW(TAG, "console command too long");
            }
            gl30_demo_sample(event.now_ms);
            const gl30_model *model=gl30_demo_state();
            gl30_motor_desire_menu(model->page==GL30_MENU && !model->off && !model->fault &&
                                  gl30_demo_display_ok(),model->menu_epoch);
        }
        /* Never advance past queued input timestamps: a sample captured during
         * painting must still be accepted on the next pass. */
        /* Read-only presentation can use the newest feedback independently of
         * the captured q/f that determines which item an input selects. */
        gl30_motor_status motor;
        gl30_motor_snapshot(&motor);
        gl30_demo_motor_feedback(motor.feedback.state,motor.feedback.fault_bits);
        int64_t tick_started_us = esp_timer_get_time();
        preferences_service((uint64_t)tick_started_us);
        if(next_frame_us==0) next_frame_us=(uint64_t)tick_started_us;
        /* Completion/spare-ready wakes may flush one immutable prepared frame
         * immediately. This never rasterizes, so presentation can overlap DMA
         * without allowing extra animation frames between 60 Hz deadlines. */
        gl30_demo_service_display((uint32_t)(tick_started_us/1000));
        if(!gl30_demo_display_ok()) gl30_motor_stop();
        bool frame_due=(uint64_t)tick_started_us>=next_frame_us;
        bool frame_blocked=false;
        if(frame_due) {
            uint64_t behind=(uint64_t)tick_started_us-next_frame_us;
            if(behind>=frame_period_us) {
                uint64_t skipped=behind/frame_period_us;
                next_frame_us+=skipped*frame_period_us;
                s_frame_deadline_drops+=(uint32_t)skipped;
            }
            gl30_demo_metrics before_raster,after_raster;
            gl30_demo_get_metrics(&before_raster);
            gl30_demo_render((uint32_t)(tick_started_us/1000));
            gl30_demo_get_metrics(&after_raster);
            bool rastered=after_raster.frames!=before_raster.frames;
            if(rastered || !gl30_demo_animation_active()) {
                /* Consume this 60 Hz slot only after it really produced a
                 * raster (or the page became static). If the frame was merely
                 * blocked by DMA/spare ownership, keep the slot due so a
                 * completion wake can retry it without creating an extra slot. */
                next_frame_us+=frame_period_us;
            } else {
                frame_blocked=true;
            }
            if(!gl30_demo_display_ok()) gl30_motor_stop();
        }
        s_last_tick_us = (uint32_t)(esp_timer_get_time() - tick_started_us);
        s_last_loop_us = (uint32_t)(esp_timer_get_time() - started_us);
        /* Rendering can become continuously runnable when the display
         * pipeline is saturated.  Yield one tick periodically (not once per
         * frame) so IDLE0 services the watchdog without imposing a 1 ms tax
         * on every presentation. Trace formatting also gets an explicit
         * yield because it can hold the main task runnable for many lines. */
        bool trace_work = gl30_display_trace_service();
        uint64_t after_work_us = (uint64_t)esp_timer_get_time();
        if (trace_work || after_work_us - s_last_idle_yield_us >= 100000U) {
            vTaskDelay(1);
            s_last_idle_yield_us = (uint64_t)esp_timer_get_time();
        }
        /* Raster cadence stays on the 16.667 ms absolute grid. DMA/spare wakes
         * are allowed to service a prepared frame, but never create a raster.
         * If ordinary work crosses a deadline by less than one full period,
         * run that due slot immediately instead of incorrectly dropping it. */
        uint64_t now_us=(uint64_t)esp_timer_get_time();
        if(frame_blocked) {
            /* Wait for DMA/spare-ready/input to free ownership, but retain a
             * short bounded fallback so a lost notification cannot stall UI. */
            (void)ulTaskNotifyTake(pdTRUE,pdMS_TO_TICKS(4));
            continue;
        }
        if(next_frame_us<=now_us) continue;
        (void)esp_timer_stop(s_frame_timer);
        ESP_ERROR_CHECK(esp_timer_start_once(s_frame_timer,next_frame_us-now_us));
        (void)ulTaskNotifyTake(pdTRUE,portMAX_DELAY);
    }
}

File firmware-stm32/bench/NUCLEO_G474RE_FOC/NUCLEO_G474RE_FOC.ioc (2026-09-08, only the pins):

Mcu.UserName=STM32G474RETx
PA0.Signal=ADC1_IN1
PA1.Signal=ADC2_IN2
PA10.Signal=S_TIM1_CH3
PA11.Signal=S_TIM1_CH4
PA13.Signal=SYS_JTMS-SWDIO
PA14.Signal=SYS_JTCK-SWCLK
PA2.Signal=USART2_TX
PA3.Signal=USART2_RX
PA5.GPIO_Label=LD2
PA5.Signal=GPIO_Output
PA8.Signal=S_TIM1_CH1
PA9.Signal=S_TIM1_CH2
PB0.Signal=ADC3_IN12
PB1.Signal=ADC1_IN12
PB12.Signal=TIM1_BKIN
PB13.Signal=TIM1_CH1N
PB14.Signal=TIM1_CH2N
PB15.Signal=TIM1_CH3N
PB3.Signal=SPI1_SCK
PB4.Signal=SPI1_MISO
PB5.Signal=SPI1_MOSI
PB6.GPIO_Label=ENC_CS
PB6.Signal=GPIO_Output
PC10.Signal=SPI3_SCK
PC11.Signal=SPI3_MISO
PC12.Signal=SPI3_MOSI
PC13.GPIO_Label=USER_BUTTON
PC13.Signal=GPIO_Input
PC7.GPIO_Label=DRV_NSLEEP
PC7.Signal=GPIO_Output
PC8.GPIO_Label=DRV_OFF
PC8.Signal=GPIO_Output
PC9.GPIO_Label=DRV_CS
PC9.Signal=GPIO_Output

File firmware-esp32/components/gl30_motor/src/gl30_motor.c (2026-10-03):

#include "gl30_motor.h"
#include "gl30_motor_arm_gate.h"
#include "safety_supervisor.h"
#include "driver/uart.h"
#include "esp_random.h"
#include "esp_timer.h"
#include "freertos/FreeRTOS.h"
#include "freertos/task.h"
#include <math.h>
#include <string.h>

/* Waveshare J1.11 U0TXD=GPIO43, J1.12 U0RXD=GPIO44, 3.3 V.
 * USB Serial/JTAG owns logs. Never send text on this binary UART. */
static const uart_port_t port=UART_NUM_0;
static portMUX_TYPE lock=portMUX_INITIALIZER_UNLOCKED;
static TaskHandle_t task;
static QueueHandle_t events;
static esp_timer_handle_t timer;
static gl30_esp_link_t link;
static gl30_menu_session session;
static gl30_motor_status status;
static gl30_motor_arm_gate_t arm_gate;
static bool desired_menu;
static uint32_t desired_epoch,tx_sequence;
static uint64_t desired_published_us;
typedef enum {
    CONTROL_DISCOVER,CONTROL_STOP_OLD,CONTROL_RELEASE,
    CONTROL_ACQUIRE,CONTROL_FIRST_ZERO,CONTROL_RUNNING,CONTROL_HELD,CONTROL_FAILED
} control_phase;
static control_phase control;
static uint64_t lease_generation,lease_counter,candidate_generation;
static uint64_t control_sent_us,control_last_tx_us,control_zero_sent_us;
static gl30_control_lease_request_t control_request;
/* Request/claim/finish are shared only through lock. The owner alone changes
 * wire state. A claim holds ARM disabled even if later feedback is lost. */
static uint64_t maintenance_token,maintenance_sequence;
static bool maintenance_claimed,maintenance_finish;

void gl30_motor_desire_menu(bool active,uint32_t epoch) {
    uint64_t now=(uint64_t)esp_timer_get_time();
    portENTER_CRITICAL(&lock);
    desired_menu=active; desired_epoch=epoch; desired_published_us=now;
    portEXIT_CRITICAL(&lock);
}
bool gl30_motor_arm(uint64_t captured_stop_generation) {
    portENTER_CRITICAL(&lock);
    bool accepted=status.control_ready &&
        gl30_motor_arm_gate_arm(&arm_gate,captured_stop_generation);
    portEXIT_CRITICAL(&lock);
    return accepted;
}
void gl30_motor_stop(void) {
    portENTER_CRITICAL(&lock); gl30_motor_arm_gate_stop(&arm_gate); portEXIT_CRITICAL(&lock);
}
uint64_t gl30_motor_maintenance_begin(void) {
    uint64_t token=0;
    portENTER_CRITICAL(&lock);
    if(status.control_ready && !status.armed && !arm_gate.arm_request &&
       maintenance_token==0 && maintenance_sequence!=UINT64_MAX) {
        gl30_motor_arm_gate_stop(&arm_gate);
        arm_gate.maintenance_active=true;
        maintenance_token=++maintenance_sequence;
        maintenance_finish=maintenance_claimed=false;
        token=maintenance_token;
    }
    portEXIT_CRITICAL(&lock);
    return token;
}
bool gl30_motor_maintenance_claim(uint64_t token) {
    bool accepted;
    portENTER_CRITICAL(&lock);
    accepted=token!=0 && token==maintenance_token && !maintenance_finish &&
        !maintenance_claimed && arm_gate.maintenance_active &&
        !arm_gate.arm_request && !status.armed && status.maintenance_ready;
    if(accepted) maintenance_claimed=true;
    portEXIT_CRITICAL(&lock);
    return accepted;
}
bool gl30_motor_maintenance_held(uint64_t token) {
    bool held;
    portENTER_CRITICAL(&lock);
    held=token!=0 && token==maintenance_token && maintenance_claimed &&
        arm_gate.maintenance_active && !maintenance_finish && !arm_gate.arm_request;
    portEXIT_CRITICAL(&lock);
    return held;
}
void gl30_motor_maintenance_end(uint64_t token) {
    portENTER_CRITICAL(&lock);
    if(token!=0 && token==maintenance_token) {
        maintenance_claimed=false; maintenance_finish=true;
        gl30_motor_arm_gate_stop(&arm_gate);
    }
    portEXIT_CRITICAL(&lock);
}
void gl30_motor_snapshot(gl30_motor_status *out) {
    uint64_t published_stop_generation;
    uint64_t now_us;
    portENTER_CRITICAL(&lock);
    *out=status;
    published_stop_generation=status.stop_generation;
    out->stop_generation=arm_gate.stop_generation;
    if(arm_gate.maintenance_active || arm_gate.arm_request || status.armed ||
       published_stop_generation!=arm_gate.stop_generation) out->zero_confirmed=false;
    portEXIT_CRITICAL(&lock);
    now_us=(uint64_t)esp_timer_get_time();
    out->feedback=gl30_motor_feedback_current(out->feedback,now_us);
    if(out->zero_confirmed &&
       (out->zero_sent_us==0u || out->zero_sent_us>now_us ||
        out->zero_feedback_us<out->zero_sent_us || now_us<out->zero_feedback_us ||
        now_us-out->zero_feedback_us>=GL30_MOTOR_FAST_FRESH_US ||
        out->feedback.state!=GL30_MOTOR_READY || out->feedback.received_us==0u ||
        now_us<out->feedback.received_us ||
        now_us-out->feedback.received_us>=GL30_MOTOR_FAST_FRESH_US)) {
        out->zero_confirmed=false;
    }
    portENTER_CRITICAL(&lock);
    out->stop_generation=arm_gate.stop_generation;
    if(out->zero_confirmed &&
       (arm_gate.maintenance_active || arm_gate.arm_request || status.armed || !status.zero_confirmed ||
        status.stop_generation!=arm_gate.stop_generation ||
        published_stop_generation!=arm_gate.stop_generation ||
        status.zero_command_nonce!=out->zero_command_nonce ||
        status.zero_sent_us!=out->zero_sent_us ||
        status.zero_feedback_us!=out->zero_feedback_us)) {
        out->zero_confirmed=false;
    }
    portEXIT_CRITICAL(&lock);
}
static void wake(void *arg) { (void)arg; xTaskNotifyGive(task); }
static bool apply_newer_stop(uint64_t *observed_stop_generation,
                             uint64_t *applied_stop_generation) {
    uint64_t live_stop_generation;
    portENTER_CRITICAL(&lock);
    live_stop_generation=arm_gate.stop_generation;
    portEXIT_CRITICAL(&lock);
    if(live_stop_generation==*observed_stop_generation) return false;
    if(control==CONTROL_RUNNING) gl30_menu_session_stop(&session);
    else session.armed=false; /* STOP is fenced now; frozen handshake stays zero. */
    *observed_stop_generation=live_stop_generation;
    *applied_stop_generation=live_stop_generation;
    return true;
}
static void owner_disarm(void) {
    gl30_motor_stop();
    gl30_menu_session_arm(&session,false);
}
static bool owner_session_step(uint64_t now_us,gl30_menu_sample *sample) {
    bool was_armed=session.armed;
    bool send=gl30_menu_session_step(&session,&link,now_us,sample);
    if(was_armed && !session.armed) gl30_motor_stop();
    return send;
}
static void control_transition(control_phase phase) {
    control=phase; control_sent_us=control_last_tx_us=control_zero_sent_us=0;
}
static bool fresh_haptic(uint64_t now,uint64_t after) {
    return after!=0 && now>=after && link.has_haptic &&
        link.last_haptic_us>=after && now>=link.last_haptic_us &&
        now-link.last_haptic_us<GL30_MOTOR_FAST_FRESH_US;
}
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

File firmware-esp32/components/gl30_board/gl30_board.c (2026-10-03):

#include "gl30_board.h"

#include <stddef.h>

#include "driver/gpio.h"
#include "driver/i2c_master.h"
#include "driver/spi_master.h"
#include "esp_attr.h"
#include "esp_async_memcpy.h"
#include "esp_err.h"
#include "esp_heap_caps.h"
#include "esp_lcd_panel_io.h"
#include "esp_lcd_panel_ops.h"
#include "esp_log.h"
#include "esp_timer.h"
#include "freertos/FreeRTOS.h"
#include "freertos/queue.h"
#include "freertos/semphr.h"
#include "freertos/task.h"

#include "esp_lcd_sh8601.h"
#include "esp_lcd_touch_cst820.h"

#define GL30_LCD_SPI_HOST SPI2_HOST
#define GL30_LCD_CS_GPIO GPIO_NUM_10
#define GL30_LCD_PCLK_GPIO GPIO_NUM_11
#define GL30_LCD_DATA0_GPIO GPIO_NUM_12
#define GL30_LCD_DATA1_GPIO GPIO_NUM_13
#define GL30_LCD_DATA2_GPIO GPIO_NUM_14
#define GL30_LCD_DATA3_GPIO GPIO_NUM_15
#define GL30_LCD_RESET_GPIO GPIO_NUM_8
#define GL30_BOARD_POWER_ENABLE_GPIO GPIO_NUM_18
#define GL30_LCD_PCLK_HZ (80U * 1000U * 1000U)

#define GL30_TOUCH_I2C_PORT I2C_NUM_1
#define GL30_TOUCH_SDA_GPIO GPIO_NUM_47
#define GL30_TOUCH_SCL_GPIO GPIO_NUM_48
#define GL30_TOUCH_RESET_GPIO GPIO_NUM_7
#define GL30_TOUCH_INT_GPIO GPIO_NUM_6
#define GL30_TOUCH_SCL_HZ 400000U

/* Two 16-row internal-RAM strips pipeline AHB-GDMA PSRAM reads with SPI DMA.
 * KK_OLED already stores RGB565 in panel MSB-first wire byte order, so staging never
 * performs per-pixel byte conversion. A strip is reused only after both its
 * SPI transfer and the next asynchronous copy reach a known completion. */
#define GL30_TRANSFER_ROWS 64U
#define GL30_TRANSFER_TIMEOUT_MS 500U
#define GL30_DISPLAY_TASK_STACK 4096U
#define GL30_DISPLAY_TASK_PRIORITY 2U
#define GL30_DISPLAY_TASK_CORE 1

static const char *TAG = "gl30_board";

typedef enum {
    GL30_DISPLAY_WORK_FRAME = 0,
    GL30_DISPLAY_WORK_POWER,
    GL30_DISPLAY_WORK_CONTRAST,
} gl30_display_work_kind;

typedef struct {
    gl30_display_work_kind kind;
    const uint16_t *pixels;
    uint32_t frame_id;
    uint64_t submit_us;
    bool asynchronous;
    bool power_on;
    uint8_t contrast;
} gl30_display_work;

typedef struct {
    bool success;
} gl30_display_control_reply;

typedef struct {
    bool success;
    uint64_t start_us;
    uint64_t final_dma_done_us;
    uint64_t done_us;
    uint32_t copy_us; /* Compatibility alias: copy_wait_us, not CPU memcpy time. */
    uint32_t copy_submit_us;
    uint32_t copy_span_us;
    uint32_t io_submit_us;
    uint32_t wait_us;
    uint32_t bytes_sent;
    uint32_t strip_count;
} gl30_transfer_result;
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

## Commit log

2026-08-30 feat: publish initial haptic control platform
    [CONTROL_HEADER_PINOUT.csv, GL30_DRV8316R_BENCH_V1_BOM.csv, GL30_DRV8316R_BENCH_V1_BOM.xlsx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]
2026-08-30 feat: add compact wireless product concept
2026-10-03 Publish current offline firmware, native A-board schematic and PCB guide
    Sync STM32/ESP32 production sources and host protocol; add current UI regressions to CI and retain frozen bench evidence boundaries. Publish the reviewed AD schematic subset without personal librarie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
    [A01_POWER_MCU.SchDoc, A01_POWER_MCU.kicad_sch, A02_DRV8316.SchDoc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]
2026-10-03 docs: align assembly PDF download name with release asset
